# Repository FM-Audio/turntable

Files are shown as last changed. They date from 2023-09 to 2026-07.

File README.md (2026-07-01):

# FM-Audio ARTA Turntable

Automatischer, netzwerkfähiger Drehteller für Lautsprecher-Directivity- und Polar-Messungen mit ARTA.

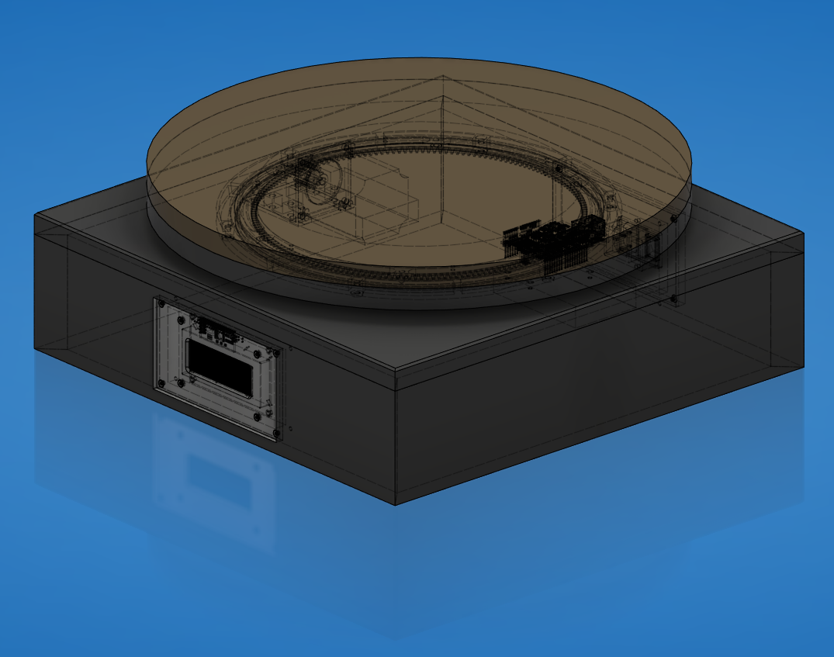
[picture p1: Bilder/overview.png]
FM-Audio Drehteller Projektübersicht


## Kurzbeschreibung

Bei der Entwicklung von Lautsprechern müssen Messungen häufig unter mehreren Winkeln durchgeführt werden, z. B. 0°, 15°, 30°, 45° oder 90°. Manuell ist das langsam, fehleranfällig und schlecht reproduzierbar.

Dieses Projekt automatisiert diesen Ablauf: ARTA steuert über ein externes Turntable-Programm einen Arduino-Drehteller an. Der Arduino fährt den Lautsprecher per Schrittmotor auf den gewünschten Winkel und zeigt IP-Adresse, Referenzfahrt und Position auf einem LCD an.

## Wofür ist das Projekt gedacht?

- Lautsprecherentwicklung
- Polar- und Directivity-Messungen
- ARTA-Gruppenmessungen
- reproduzierbare Winkelmessungen
- Messräume, bei denen Bedienplatz und Drehteller räumlich getrennt sind

## Funktionsprinzip

1. Der Arduino erhält per DHCP eine IP-Adresse.
2. Die IP-Adresse wird auf dem Display angezeigt.
3. Beim Start führt der Drehteller eine Referenzfahrt aus.
4. ARTA ruft das externe Turntable-Programm `turntable.exe` auf.
5. Das Programm sendet den Zielwinkel per UDP an den Arduino.
6. Der Arduino berechnet daraus die benötigten Motorschritte.
7. Der Schrittmotor fährt die gewünschte Position an.
8. Der Arduino sendet eine Rückmeldung zurück.

```text
ARTA -> turntable.exe -> Netzwerk/UDP -> Arduino -> TB6600 -> NEMA23 -> Drehteller
```

## Projektinhalt

| Pfad | Inhalt |
|---|---|
| [`Arduino/`](Arduino/) | Arduino-Sketch für Ethernet, UDP, Display, Referenzfahrt und Motorsteuerung |
| [`ARTA Turntable File/`](ARTA%20Turntable%20File/) | Windows-Datei `turntable.exe` für die ARTA-Anbindung inkl. benötigter DLLs |
| [`Bilder/`](Bilder/) | Anschlussplan, Screenshots und Fotos |
| [`DXF/`](DXF/) | CAD-/Fräs-/Laser-Dateien |
| [`STL/`](STL/) | 3D-Druck-Dateien für Halter und Abstandshalter |
| [`Bestellliste.xlsx`](Bestellliste.xlsx) | Stückliste / Einkaufsliste |
| [`Drehteller Dokument.docx`](Drehteller%20Dokument.docx) | ursprüngliche Projektdokumentation |
| [`ARTA Manual/`](ARTA%20Manual/) | ARTA-Dokumentation zur Turntable-/Polar-Messung |
| [`Drehteller.zip`](Drehteller.zip) | STEP/CAD-Datei |
| [`docs/downloads.md`](docs/downloads.md) | Download-Hinweise für Windows, Linux, ARTA, CAD/DXF/STL |

## Downloads

| Ziel | Download / Datei |
|---|---|
| Komplettes Projekt | GitHub `Code` → `Download ZIP` |
| REW-GUI für Windows | GitHub `Releases` → `FM-Audio-REW-Turntable-Windows.zip` |
| REW-GUI für Linux/CachyOS inkl. Desktop-Icon | GitHub `Releases` → `FM-Audio-REW-Turntable-Linux.zip` |
| ARTA-Treiber | [`ARTA Turntable File/turntable.exe`](ARTA%20Turntable%20File/turntable.exe) |
| STEP/CAD | [`Drehteller.zip`](Drehteller.zip) |
| DXF | [`DXF/`](DXF/) |
| STL | [`STL/`](STL/) |

Linux-Desktop-Starter: Im Linux-ZIP liegt `install_desktop_launcher_linux.sh`. Nach dem Ausführen erscheint der Starter als **FM-Audio REW Turntable** im Anwendungsmenü. Details: [`docs/downloads.md`](docs/downloads.md).

## Hardwareüberblick

| Komponente | Beispiel / Hinweis |
|---|---|
| Mikrocontroller | Arduino Ethernet oder Arduino Uno R3 + Ethernet Shield |
| Motor | NEMA23-Schrittmotor, ca. 2 Nm, 8-mm-Welle |
| Motortreiber | TB6600 CNC Stepper Driver |
| Netzteil Motor | Mean Well LRS-100-24, 24 V |
| Netzteil Logik | Mean Well 5 V, z. B. RS-15-5 oder vergleichbar |
| Display | I2C LCD 20x4, Adresse im Code aktuell `0x27` |
| Referenzsensor | Näherungssensor / Endlagensensor |
| Mechanik | Drehkranz, Zahnrad/Ritzel, MDF-/Alu-Platten, 3D-Druckhalter |

Die detaillierte Einkaufsliste liegt in [`Bestellliste.xlsx`](Bestellliste.xlsx).

## Pinbelegung Arduino

| Funktion | Arduino-Pin | Hinweis |
|---|---:|---|
| STEP / PULSE | D2 | zum TB6600 `PUL` / `STEP` |
| Referenzsensor | D3 | `INPUT_PULLUP`, erwartet HIGH/LOW-Wechsel |
| DIRECTION | D5 | zum TB6600 `DIR` |
| ENABLE | D8 | im Sketch definiert |
| LCD | I2C SDA/SCL | I2C-Display 20x4 |
| Netzwerk | Ethernet Shield / Arduino Ethernet | UDP-Port `10049` |

Mehr Details: [`docs/wiring.md`](docs/wiring.md)

## Wichtige Arduino-Werte

Im Sketch [`Arduino/Arta_TurntablemitStepperundDisplay20230803.ino`](Arduino/Arta_TurntablemitStepperundDisplay20230803.ino):

```cpp
unsigned int localPort = 10049;
float Stepsprograd = 65.75;
```

`Stepsprograd` ist der wichtigste Kalibrierwert. Er beschreibt, wie viele Motorschritte für 1° Drehtellerbewegung nötig sind.

Der Wert hängt ab von:

- Motorschritten pro Umdrehung
- Microstepping am TB6600
- Zahnrad/Ritzel
- Drehkranz-Übersetzung

Kalibrierung: [`docs/calibration.md`](docs/calibration.md)

## Arduino flashen

1. Arduino IDE installieren: <https://www.arduino.cc/en/software>
2. Benötigte Libraries installieren:
   - `Ethernet`
   - `EthernetUdp`
   - `LiquidCrystal_I2C`
   - `AccelStepper`
3. Datei öffnen:
   - [`Arduino/Arta_TurntablemitStepperundDisplay20230803.ino`](Arduino/Arta_TurntablemitStepperundDisplay20230803.ino)
4. Board und Port auswählen.
5. Sketch hochladen.
6. Arduino neu starten.
7. Auf dem Display prüfen:
   - DHCP erfolgreich?
   - IP-Adresse sichtbar?
   - Referenzfahrt abgeschlossen?

## ARTA einrichten

1. ARTA starten.
2. Menü öffnen:
   - `Setup` → `Rotating turntable`
3. `External` auswählen.
4. Als Turntable-Programm eintragen:
   - `ARTA Turntable File/turntable.exe`
5. Falls ARTA die Datei nicht direkt auswählbar macht, den Pfad manuell eintragen.

Mehr Details: [`docs/arta-setup.md`](docs/arta-setup.md)

## Messung durchführen

1. ARTA öffnen.
2. `Record` → `Spatial impulse response group record`
3. Turntable Driver auswählen.
4. Messordner erstellen und auswählen.
5. Winkelauflösung wählen, z. B. `15°`.
6. Endwinkel wählen, z. B. `45°`, `90°` oder `180°`.
7. Pause setzen, z. B. `3 s`.
8. Dateinamen prüfen.
9. Messung starten.

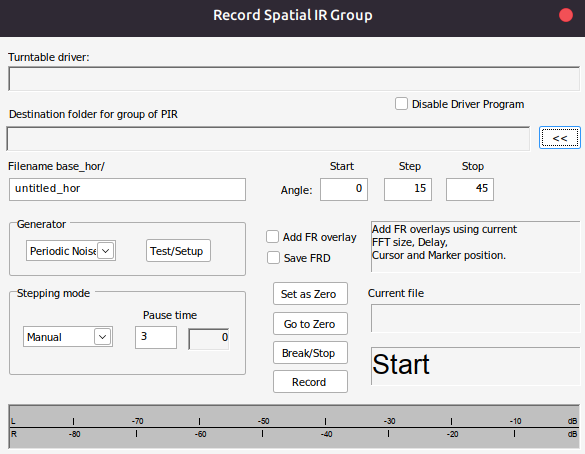
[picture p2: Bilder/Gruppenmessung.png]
ARTA Gruppenmessung


## REW-Integration

REW 5.40+ besitzt eine HTTP-API. Dadurch kann der vorhandene Arduino-Drehteller auch mit Room EQ Wizard genutzt werden.

Das Python-Script liegt hier:

```text
software/rew_turntable/rew_turntable_runner.py
```

Dokumentation: [`docs/rew-integration.md`](docs/rew-integration.md)

Kurzbeispiel für den aktuell geprüften Turntable:

```bash
python software/rew_turntable/rew_turntable_runner.py \
  --turntable-ip 192.168.178.191 \
  --mode manual \
  --angles 0:180:15
```

Für die Werkstattbedienung mit frei einstellbarem Start-/Endwinkel, Schrittweite und REW-Frequenzbereich gibt es zusätzlich:

```bash
python software/rew_turntable/rew_turntable_gui.py
```

Unter Windows und Linux gibt es vorbereitete Download-Pakete:

| Variante | Download/Start |
|---|---|
| Fertige Windows-EXE | GitHub Release `FM-Audio-REW-Turntable-Windows.zip` herunterladen und `FM-Audio-REW-Turntable.exe` starten |
| Linux/CachyOS-Paket | GitHub Release `FM-Audio-REW-Turntable-Linux.zip` herunterladen, `run_gui_linux.sh` starten oder `install_desktop_launcher_linux.sh` für den Desktop-Starter ausführen |
| Python-Version | `software\rew_turntable\run_gui_windows.bat` doppelklicken oder unter Linux `software/rew_turntable/run_gui_linux.sh` starten |

Die Windows-EXE und das Linux-Paket werden automatisch über `.github/workflows/build-windows.yml` gebaut.

## Dokumentation

| Dokument | Zweck |
|---|---|
| [`docs/downloads.md`](docs/downloads.md) | Download-Pakete und Startdateien für Windows/Linux |
| [`docs/build-guide.md`](docs/build-guide.md) | Aufbau und Projektüberblick |
| [`docs/wiring.md`](docs/wiring.md) | Anschluss, Pins und Verdrahtung |
| [`docs/arta-setup.md`](docs/arta-setup.md) | Einrichtung in ARTA |
| [`docs/rew-integration.md`](docs/rew-integration.md) | REW-API-Anbindung und Python-Script |
| [`docs/calibration.md`](docs/calibration.md) | Kalibrierung von `Stepsprograd` |
| [`docs/troubleshooting.md`](docs/troubleshooting.md) | Fehlersuche |

## Sicherheitshinweis

In diesem Projekt werden Netzteile verwendet, die mit Netzspannung betrieben werden können.

**230-V-Arbeiten dürfen nur von fachkundigen Personen durchgeführt werden.**

Vor dem Einschalten prüfen:

- Netzteile korrekt angeschlossen?
- 24-V- und 5-V-Seite getrennt und sauber verdrahtet?
- gemeinsame Masse nur dort verbunden, wo sinnvoll?
- Motortreiber korrekt eingestellt?
- Not-Aus / Abschaltmöglichkeit vorhanden?

## Bekannte Verbesserungsmöglichkeiten

- Python-Quellcode zu `turntable.exe` ergänzen.
- README-Bilder weiter optimieren und verkleinern.
- GitHub Release mit versionierten ZIP-Dateien ergänzen, damit Nutzer nicht auf zeitlich begrenzte Actions-Artefakte angewiesen sind.
- Arduino-Code stärker kommentieren und Konstanten in einen Konfigurationsblock verschieben.
- Mechanik-Maße und Montage-Reihenfolge noch ausführlicher dokumentieren.

## Lizenz

Dieses Projekt steht unter der [`FM-Audio Non-Commercial Source License 1.0`](LICENSE).

Kurzfassung:

| Erlaubt | Nicht erlaubt |
|---|---|
| private Nutzung | kommerzielle Nutzung |
| Lernen / Evaluieren / Hobby | Verkauf von Produkten, Kits, CAD-Dateien oder Software |
| nicht-kommerzielle Änderungen | bezahlte Fertigung, Messung, Kalibrierung, Support oder Beratung |
| nicht-kommerzielle Weitergabe unter gleicher Lizenz | Nutzung in kommerziellen Kunden-/Firmenprojekten |

Es wird **keine Patentlizenz** gewährt. Für kommerzielle Nutzung, Patentrechte oder Sonderfreigaben bitte schriftlich anfragen: `turntable@fm-audio.eu`.

## Credits

FM-Audio — Stefan Weltermann, Nils Hitschke

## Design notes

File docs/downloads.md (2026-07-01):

# Downloads

Dieses Repository enthält Hardware-Dateien, Firmware und Software-Starter für den FM-Audio Drehteller.

## Schnellübersicht

| Paket / Datei | Zweck | Wo herunterladen? |
|---|---|---|
| Komplettes Projekt | Firmware, CAD, Bilder, Doku, Software | GitHub: `Code -> Download ZIP` |
| Windows GUI | Fertige `FM-Audio-REW-Turntable.exe` für REW | GitHub `Releases` -> `FM-Audio-REW-Turntable-Windows.zip` |
| Linux GUI + Desktop-Icon | Python/Tkinter-GUI, Shell-Starter, `.desktop`-Launcher | GitHub `Releases` -> `FM-Audio-REW-Turntable-Linux.zip` |
| ARTA-Treiber | Klassische ARTA-Datei `turntable.exe` | Im Repo: `ARTA Turntable File/turntable.exe` |
| STEP/CAD | STEP-Datei für den Drehteller | Im Repo: `Drehteller.zip` |
| DXF-Dateien | Fräs-/Laser-Dateien | Im Repo: `DXF/` |
| STL-Dateien | 3D-Druckteile | Im Repo: `STL/` |

## Windows

1. Auf GitHub den Bereich `Releases` öffnen:

```text
https://github.com/FM-Audio/turntable/releases
```

2. Das Windows-Paket herunterladen:

```text
FM-Audio-REW-Turntable-Windows.zip
```

3. ZIP entpacken und starten:

```text
FM-Audio-REW-Turntable.exe
```

## Linux / CachyOS / Arch

1. Auf GitHub den Bereich `Releases` öffnen:

```text
https://github.com/FM-Audio/turntable/releases
```

2. Das Linux-Paket herunterladen:

```text
FM-Audio-REW-Turntable-Linux.zip
```

3. ZIP entpacken.
4. Voraussetzungen installieren, z. B. auf CachyOS/Arch:

```bash
sudo pacman -S python tk
```

5. Direkt starten:

```bash
chmod +x run_gui_linux.sh
./run_gui_linux.sh
```

6. Optional Desktop-Icon installieren:

```bash
chmod +x install_desktop_launcher_linux.sh
./install_desktop_launcher_linux.sh
```

Danach gibt es einen Anwendungsstarter:

```text
FM-Audio REW Turntable
```

## Actions-Artefakte

Zusätzlich erzeugt der Workflow `Build GUI Downloads` weiterhin GitHub-Actions-Artefakte. Für normale Nutzer sind aber die Dateien im Bereich `Releases` der empfohlene Download-Weg.

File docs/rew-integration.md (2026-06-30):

# REW-Integration für den FM-Audio Turntable

Der bestehende Drehteller wurde ursprünglich für ARTA gebaut. REW 5.40+ besitzt inzwischen eine HTTP-API, dadurch kann der Drehteller auch mit REW automatisiert werden.

## Kurzfazit

Ja, die Anbindung ist möglich.

Für den vollautomatischen Betrieb muss in REW eine **Pro-Upgrade-Lizenz** hinterlegt sein. Das ist wichtig für Benutzer des GitHub-Repos:

- automatische Sweeps per API: `POST /measure/command {"command": "SPL"}`
- Sweep-Frequenzbereich per API setzen: `PUT /measure/sweep/configuration`

Ohne Pro bleibt der manuelle Modus nutzbar: Das Programm dreht den Teller und wartet, bis der Benutzer in REW eine Messung gestartet/gespeichert hat.

Es gibt drei Betriebsarten:

| Modus | Voraussetzung | Ablauf |
|---|---|---|
| `auto` | REW 5.40+ API + REW Pro Upgrade | Programm dreht den Teller, startet den REW-Sweep per API, wartet bis die Messung fertig in REW erscheint, dreht weiter |
| `manual` | REW 5.40+ API, keine Pro-Lizenz nötig | Programm dreht den Teller, Bediener startet Messung in REW, Programm erkennt neue Messung |
| `turntable-only` | nur Netzwerk zum Arduino | Programm dreht nur den Teller |

Wichtig: Laut REW-Dokumentation sind GET-Zugriffe frei nutzbar. Schreibende API-Aktionen wie Sweep-Konfiguration und automatisierte Sweep-Messungen benötigen das REW-Pro-Upgrade.

## Architektur

```text
REW 5.40+ API  <---- HTTP localhost:4735 ---->  rew_turntable_runner.py
                                                        |
                                                        | UDP Port 10049
                                                        v
Arduino Turntable  <---- TB6600 ---->  NEMA23 / Drehteller
```

Der Arduino-Code muss dafür zunächst nicht geändert werden. Er versteht bereits UDP-Kommandos mit Winkelwerten.

## Vorhandenes Arduino-Protokoll

Im Arduino-Sketch:

```cpp
unsigned int localPort = 10049;
float Stepsprograd = 65.75;
```

Der Arduino erwartet per UDP einen Winkel als ASCII-Text, z. B.:

```text
0
15
30
-15
```

Danach fährt er auf diese Position und sendet eine kurze Textantwort zurück.

## REW API starten

### Windows

```powershell
"C:\Program Files\REW\roomeqwizard.exe" -api
```

Oder in den REW-Einstellungen:

```text
Preferences -> API -> Start API server
```

Standardadresse:

```text
http://127.0.0.1:4735
```

Die Swagger-/API-Doku ist dann im Browser erreichbar:

```text
http://localhost:4735
```

### Prüfen

Auf dem REW-PC:

```powershell
curl http://127.0.0.1:4735/application/commands
```

Wenn JSON zurückkommt, läuft die API.

## REW wie ARTA nutzen

ARTA hat eine eingebaute Gruppenmessung:

```text
Record -> Spatial impulse response group record
```

Dort stellt man z. B. `0°` bis `90°` in `15°`-Schritten ein. ARTA ruft dann für jeden Winkel `turntable.exe` auf.

REW hat aktuell keine identische eingebaute Turntable-Dialogbox. Die entsprechende Lösung ist daher ein **kleiner externer Ablaufstarter**:

```text
rew_turntable_runner.py
```

Der Ablaufstarter übernimmt das, was bei ARTA die Gruppenmessung macht:

1. Winkelreihe erzeugen, z. B. `0, 15, 30, 45, 60, 75, 90`.
2. Drehteller per UDP auf den Zielwinkel fahren.
3. Einschwingzeit abwarten.
4. REW-Messung starten oder auf manuell gestartete REW-Messung warten.
5. Messung mit Winkelname/Notiz versehen.
6. Zum nächsten Winkel gehen.

Damit sieht der REW-Ablauf praktisch so aus:

```bash
python software/rew_turntable/rew_turntable_runner.py \
  --turntable-ip 192.168.178.191 \
  --mode manual \
  --angles 0:90:15 \
  --settle-s 3 \
  --name-template "Angle {angle} deg"
```

Für den Standardfall liegt zusätzlich ein Starter-Script im gleichen Ordner:

```bash
software/rew_turntable/run_0_90_15_manual.sh
```

Für den normalen Werkstattbetrieb gibt es außerdem ein kleines Desktop-Fenster:

```bash
python software/rew_turntable/rew_turntable_gui.py
```

Dort können Startwinkel, Endwinkel, Schrittweite und der REW-Frequenzbereich frei eingegeben werden, z. B.:

```text
Start: 0°
Ende:  135°
Schritt: 10°
Startfrequenz: 2000 Hz
Endfrequenz: 20000 Hz
```

Der Frequenzbereich wird über die REW-API gesetzt:

```http
PUT /measure/sweep/configuration
{"startFrequency": 2000, "endFrequency": 20000, "length": "512k"}
```

Das ist z. B. für Hochtöner sinnvoll, damit kein unnötiger Tieftonanteil im Sweep liegt.

Das erzeugt die Reihe:

```text
0°, 10°, 20°, 30°, 40°, 50°, 60°, 70°, 80°, 90°, 100°, 110°, 120°, 130°, 135°
```

Wenn der Endwinkel nicht genau auf dem Raster liegt, wird er als letzter Winkel zusätzlich angefahren. So funktioniert `0°` bis `135°` mit `10°` Schritten wie erwartet.

Für den Bediener ist das die REW-Entsprechung zu ARTA `Start` in der Gruppenmessung.

## Script verwenden

Das Script liegt hier:
```text
software/rew_turntable/rew_turntable_runner.py
```

### Nur Drehteller testen

```bash
python software/rew_turntable/rew_turntable_runner.py \
  --turntable-ip 192.168.178.191 \
  --mode turntable-only \
  --angles 0
```

### Manuell mit REW messen

Dieser Modus braucht keine REW-Pro-Lizenz für automatische Sweeps.

```bash
python software/rew_turntable/rew_turntable_runner.py \
  --turntable-ip 192.168.178.191 \
  --mode manual \
  --angles 0:180:15 \
  --settle-s 3
```

Ablauf:

1. Script fährt Winkel 0° an.
2. Script wartet 3 Sekunden.
3. Bediener startet in REW die Messung.
4. Script erkennt, dass eine neue Messung in REW entstanden ist.
5. Script fährt zum nächsten Winkel.
6. Wiederholen bis Endwinkel erreicht ist.

### Vollautomatisch mit REW Pro

```bash
python software/rew_turntable/rew_turntable_runner.py \
  --turntable-ip 192.168.178.191 \
  --mode auto \
  --angles 0:180:15 \
  --settle-s 3 \
  --start-frequency 2000 \
  --end-frequency 20000 \
  --sweep-length 512k
```

Dieser Modus läuft so ab:

1. REW-Sweepbereich konfigurieren, z. B. 2000–20000 Hz.
2. Drehteller auf den Zielwinkel fahren.
3. Einschwingzeit abwarten.
4. REW-API-Befehl senden:

```http
POST /measure/command
{"command": "SPL"}
```

5. Warten, bis in REW eine neue Messung unter `/measurements` erscheint.
6. Erst dann zum nächsten Winkel fahren.

Wenn REW meldet, dass die Lizenz nicht ausreicht, `--mode manual` verwenden oder REW Pro aktivieren.

## Wenn REW auf einem anderen Rechner läuft

Die REW-API ist standardmäßig nur lokal erreichbar. Am einfachsten ist daher:

- Python-Script direkt auf dem REW-PC ausführen.
- Der REW-PC muss den Arduino per Netzwerk erreichen können.

Alternativ kann REW mit Host-Bindung gestartet werden:

```powershell
"C:\Program Files\REW\roomeqwizard.exe" -api -host "0.0.0.0"
```

Dann Firewall und Netzwerkfreigabe beachten.

## Aktuell geprüfter Turntable

Im lokalen Netzwerk wurde der Arduino anhand der im Sketch definierten MAC-Adresse gefunden:

```text
MAC: b8:96:74:01:02:03
IP:  192.168.178.191
Port: 10049/UDP
```

Ein sicherer Test mit Winkel `0` lieferte eine UDP-Antwort vom Arduino.

## Nächste technische Verbesserungen

- Arduino-Antwort verlängern: Der aktuelle Antwortpuffer ist sehr kurz und schneidet den Text ab.
- Optional Statuskommando ergänzen, z. B. `status`, ohne Bewegung.
- Optional `home`/`reference`-Kommando ergänzen.
- Optional Zielwinkel erst bestätigen, wenn die Position wirklich erreicht wurde.
- Python-Script später als Windows-EXE paketieren.

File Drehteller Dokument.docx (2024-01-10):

ARTA Drehteller

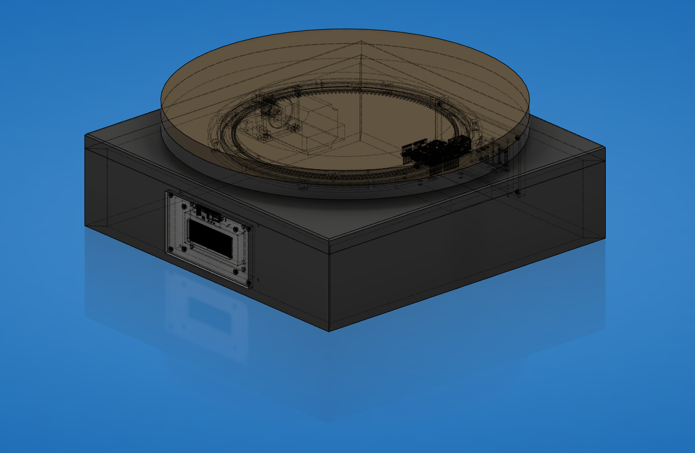
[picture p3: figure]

Problemstellung:

Beim Entwickeln von Lautsprechern und zum Beurteilen des Abstrahlverhaltens ist es notwendig verschiedene Winkel eines Lautsprechers zu messen und zu untersuchen.

Dies stellt man typischerweise mit manuellen Drehtellern an.

Im professionellen Bereich arbeitet man mit automatisierten Drehtellern, zum Teil sogar mit mehreren, um Ballonmessungen anfertigen zu können.

Bei der manuellen Variante, muss die Messung in der Regel auch manuell gestartet, ein Filename benannt und der Lautsprecher weitergedreht werden. Entwicklungen sind häufig ein iterativer Prozess und müssen dann mehrfach wiederholt werden.

Um sich Zeit zu sparen, haben wir uns einen automatisierten Drehteller entwickelt, welcher an den ARTA Drehteller aus dem ARTA Annex angelehnt ist.

Folgende Punkte haben uns aber gestört, bzw. wollten wir anders machen:

1. Standard Hardware

Das Ziel war es mit typischer und gut erhältlicher und günstiger Hardware zu arbeiten.

Daher haben wir uns für den Arduino R3 mit Ethernet Shield bzw. für ein Arduino Ethernet mit USB2Serial Board entschieden. Die Bespielung des ATMega 328 funktioniert dabei über die erhältliche Arduino IDE Software. Als Schrittmotor kam ein günstiger Nema23 mit 2Nm Drehmoment in Frage mit einem 21 Zahn Stirnrad.

2. Netzwerkgebunde Software

Bei semi -und professionellen Messungen ist oft der Messraum vom Bedienraum getrennt.

Die klassischen Lösung sieht eine USB Schnittstelle vor, die nicht ewig verlängert werden kann. Meist ist nach 5Metern Schluss. Daher bezieht unsere Lösung eine IP Adresse über einen DHCP Server. Es muss nur ein Netzwerkkabel angeschlossen werden und die IP Adresse wird dann über das eingebaut Display angezeigt. So ist es möglich entfernte Strecken zu überwinden.

3. Optische Anzeige

Ein Display ist zwar nicht zwangsläufig notwendig, allerdings ist es schön ein Feedback vom Drehteller zu bekommen. Angezeigt werden: Die aktuelle IP Adresse, Referenzfahrt, Referenzfahrt durchgeführt und die aktuelle Position bzw. deren Gradzahl.

Im Anhang findet ihr folgende Dinge:

DXF Zeichnungen von Displayplatte, Halteplatte Schrittmotor, Rückplatte

STL Files für Abstandshalter und Rückplatte

Stückliste und Bezugsmöglichkeiten

Programmcode Arduino

Programmcode Python Anbindung ARTA

Das Projekt wird als OpenSource veröffentlicht und es ist jedem frei die Software nach seinen Belieben zu ändern und anders zu gestalten.

Installation des Programms auf dem Arduino

1. Runterladen der Arduino IDE Software

https://www.arduino.cc/en/software

2. Öffnen der Arta_Turntable_xx.ino

3. Board auswählen

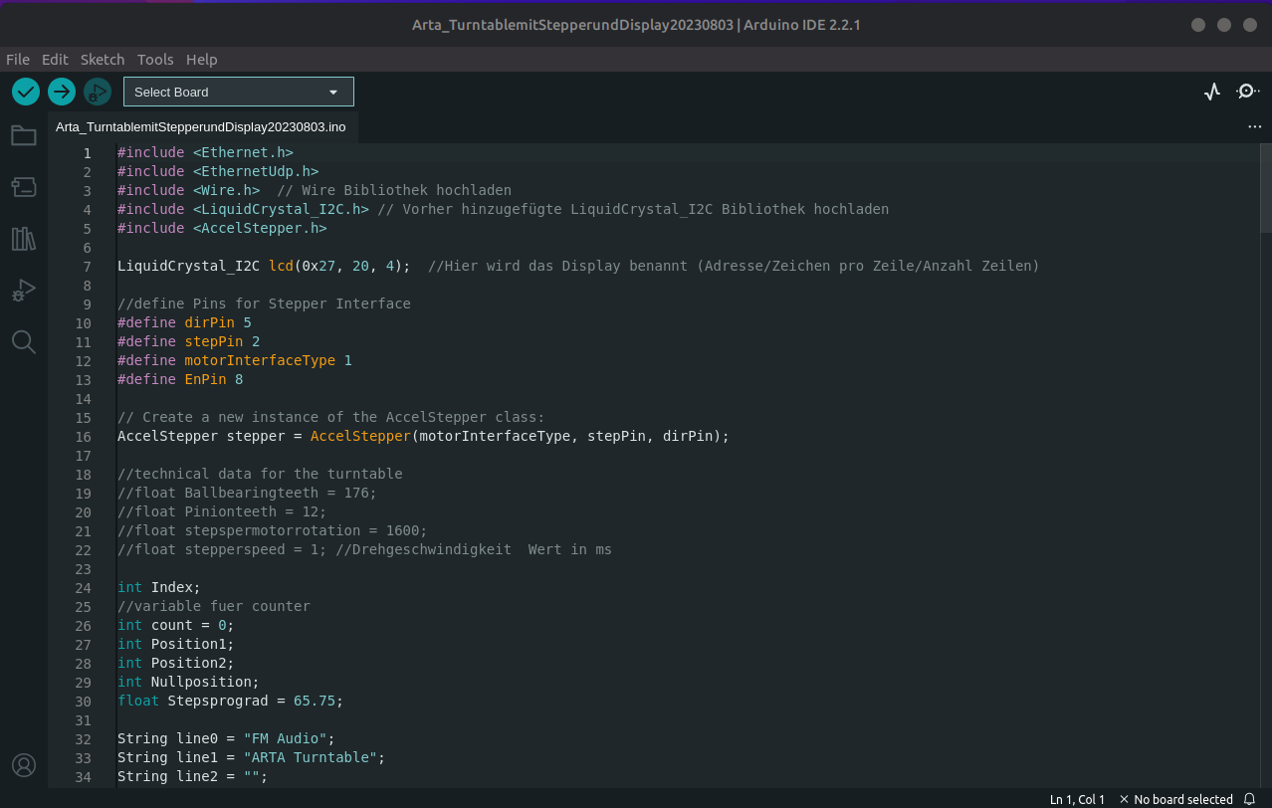
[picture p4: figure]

4. Upload des Codes auf den Arduino

ARTA Turntable Programm integrieren

1. Starte die ARTA Messsoftware

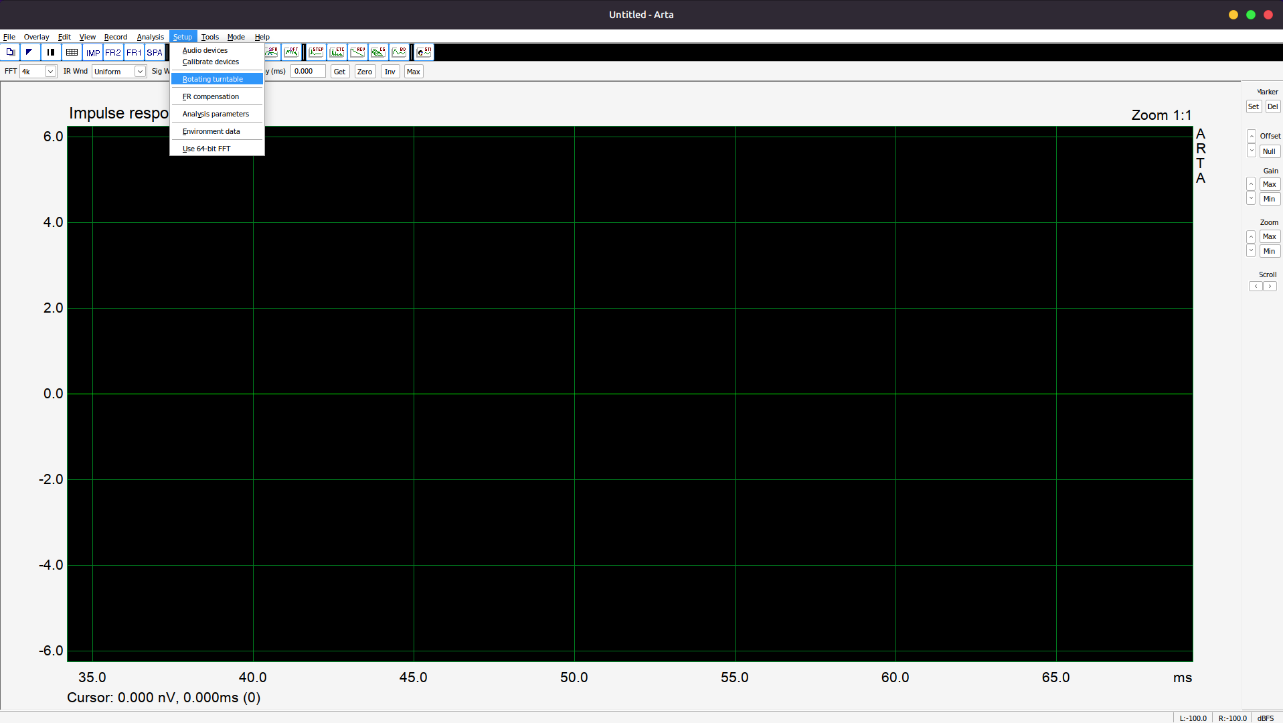
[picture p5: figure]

2. Setup > Rotating turntable

3. Auswahl External > Browse File > turntable.exe aus Ordner wählen.

Die .exe Datei kann nicht angeklickt werden sondern muss manuell eintragen werden.

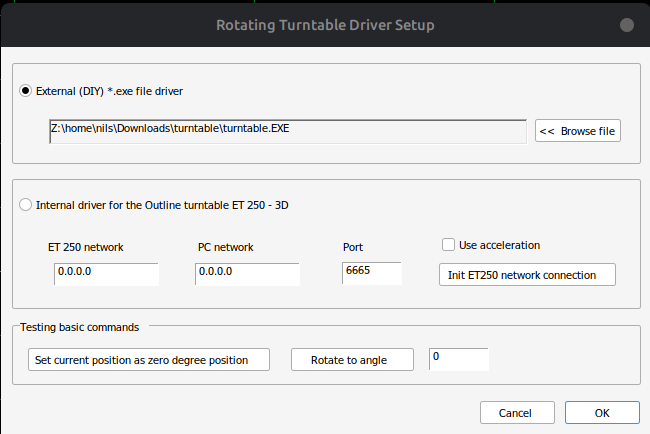
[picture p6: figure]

Messung durchführen


1. Record > Spatial impulse response group record

2. Turntable driver auswählen

3. Ordner für die PIR Messung erstellen und auswählen

4. Winkelauflösung einstellen (Standard 15Grad)

5. Endwinkel angeben (Standard 45Grad)

6. Pause von 3 Sekunden eintragen

7. Gegenbefalls Filename abändern

8. Start

Anschließen und Verbinden des Schrittmotors und der Kabel

Schrittmotor auf Arduino

stepPin = 2

dirPin = 5

EnPin = 8

Spannungsteiler = 3

Widerstände =

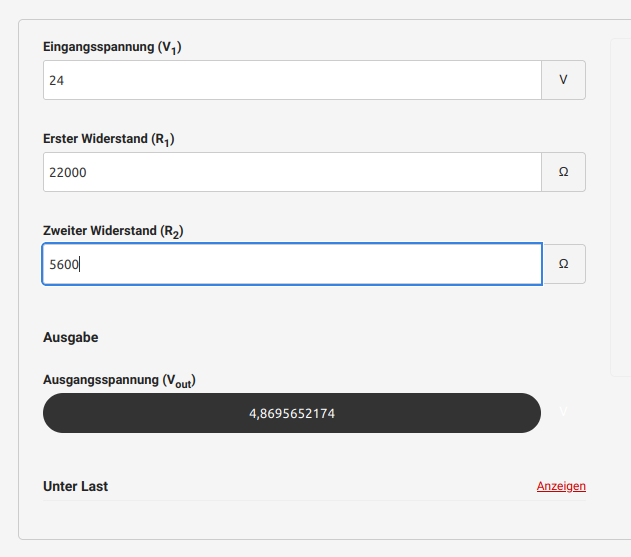
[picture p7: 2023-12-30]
Bilder/Spannungsteiler.png

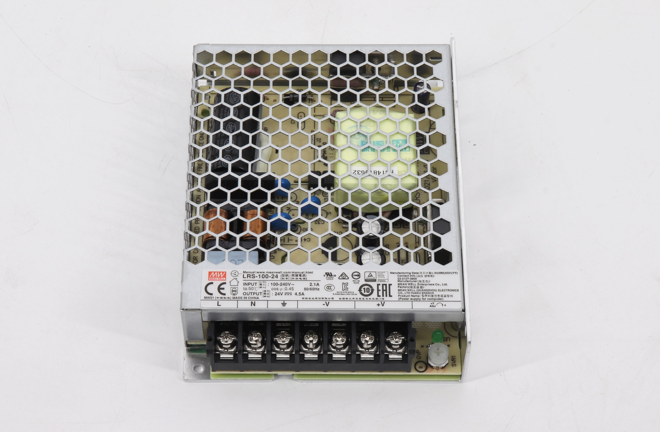
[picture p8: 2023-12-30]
Bilder/LRS24V.jpg

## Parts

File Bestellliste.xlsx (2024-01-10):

Stückliste | Bauteil | Bezeichnung | Preis | Anbieter | Hersteller | Bemerkung
1 | Zahnkranz | https://www.drehteller.com/drehkraenze/alu-druckguss/61/drehkranz-alu-druckguss-330-mm-sandgestrahlt?c=15 | 36.95 € | Hefter Fertigungstechnik
2 | Mikrocontroller | https://store.arduino.cc/products/arduino-ethernet-shield-2 | 17.99 € | Amazon | Arduino
 | Mikrocontroller |  |  | Amazon | Arduino | Alternative zu 1
3 | Zahnrad | https://www.maedler.de/Article/21801100 | 15.15 € | Hefter Fertigungstechnik | Mädler | 1600-0300.01 | Außen 21mm, Bohrung 8mm, Werkstoff C45
4 | Aluwinkel | Baumarkt/ebay | 5.00 € | ebay |  | Muss angepasst werden
5 | Holz | MDF schwarz | 15.00 € | Baumarkt
6 | Schrauben | Holzschrauben 4x25mm | 5.00 € | Baumarkt
7 | Schrittmotor | 23HS8430D8P1-5 | 13.29 € | ACT Motor |  | 8mm Aufnahme nicht 6mm
8 | Netzteil 12V | Schaltnetzteil LRS-100-24 - 108W 24V | 22.00 € | Amazon | Meanwell
9 | Netzteil 5V | Schaltnetzteil RS-15-5 3A | 10.97 € | Pollin | Meanwell
10 | Kabel | Steckboard-Verbindungsleitungen | 2.96 € | Pollin
11 | Schrittmotortreiber | Schrittmotortreiber TB6600CNC | 11.55 € | ebay
12 | Widerstände | Widerstände für Spannungsteiler | 0.40 € | Pollin
13 | Abstandshalter | Abstandsbolzen Polyamid 5,6mm M3x0,5 8mm | 0.07 € | Pollin
14 | Stiftleiste | Stiftleiste 2x20Polig | 0.32 € | Pollin | zum anlöten der Kabel
15 | Steckbrücken | Steckbrücken Sortiment | 3.60 € | Pollin | Kabel

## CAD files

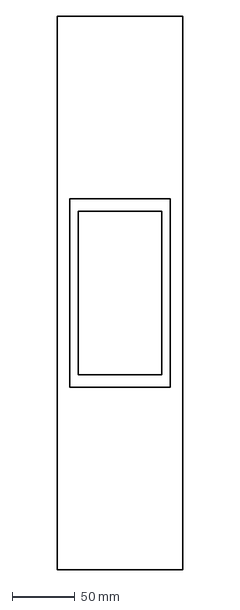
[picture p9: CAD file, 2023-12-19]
DXF/Kasten_Front_2004.dxf
100.0 x 440.0 mm

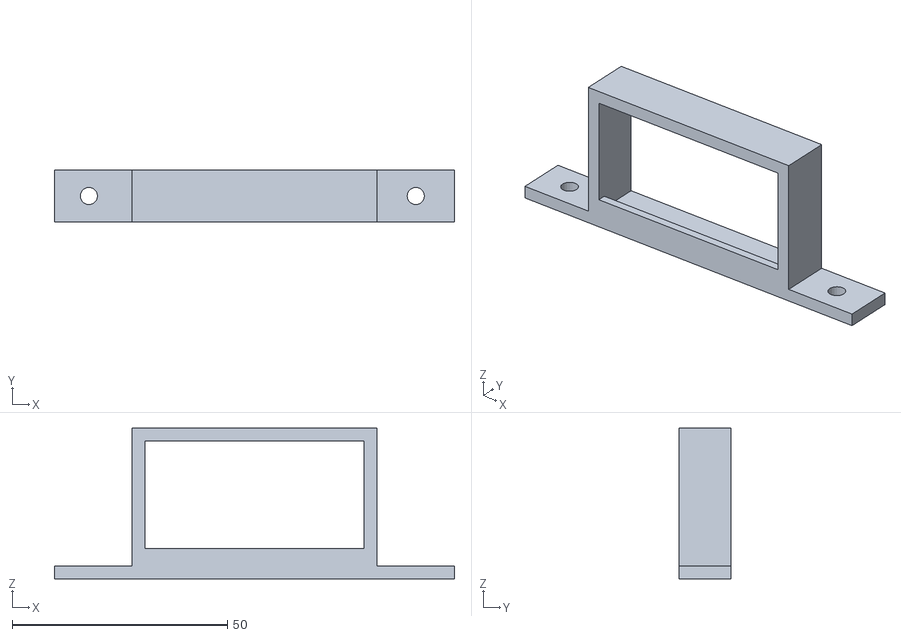
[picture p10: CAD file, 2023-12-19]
STL/Mean_Well_RS_Holder_Rear.stl
93.0 x 12.0 x 35.0

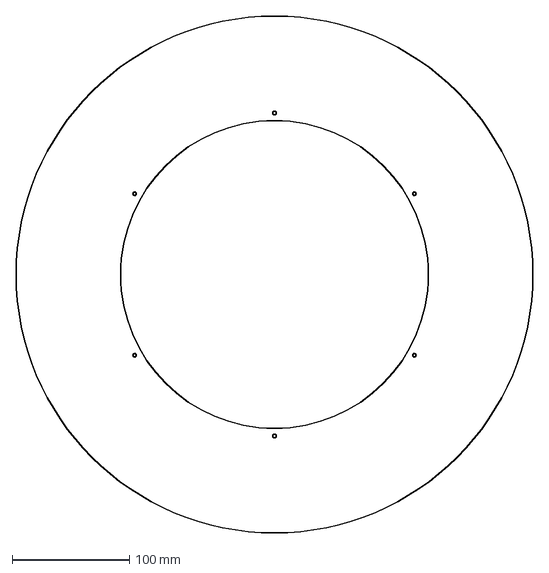
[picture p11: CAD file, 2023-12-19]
DXF/Zwischenring3_neu.dxf
440.0 x 440.0 mm

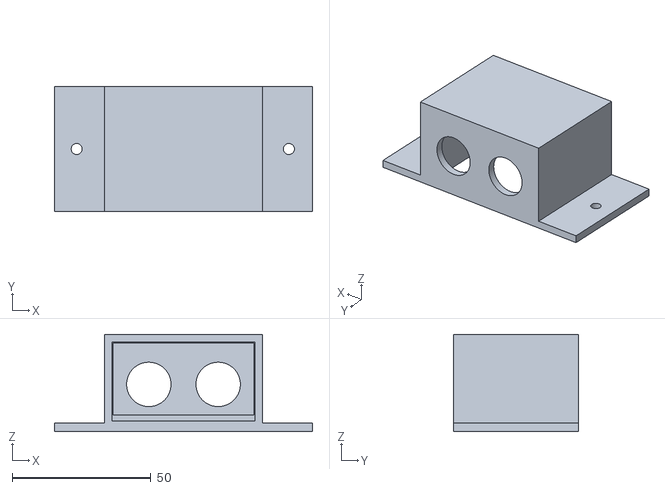
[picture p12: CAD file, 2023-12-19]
STL/Mean_Well_RS_Holder_Front.stl
93.0 x 45.0 x 35.0

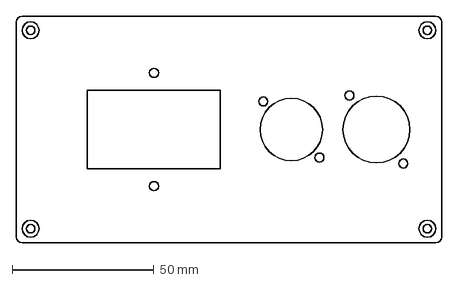
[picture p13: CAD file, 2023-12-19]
DXF/Displayplatte_Neutrik.dxf
150.0 x 80.0 mm

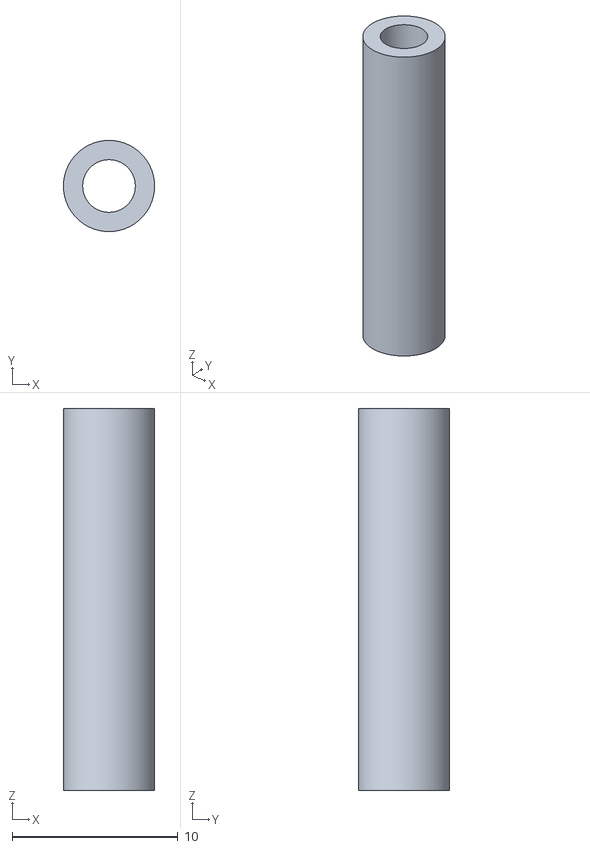
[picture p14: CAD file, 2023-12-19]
STL/Abstandshalter Arduino.stl
5.50 x 5.50 x 23.0

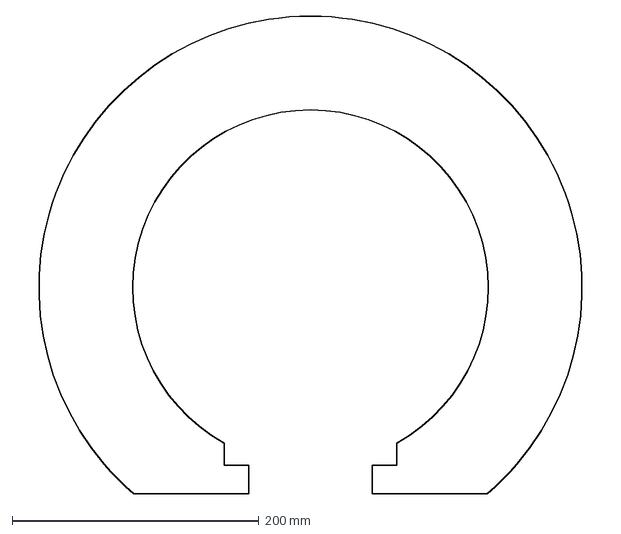
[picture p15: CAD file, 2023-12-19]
DXF/Zwischenring2.dxf
476.5 x 387.0 mm

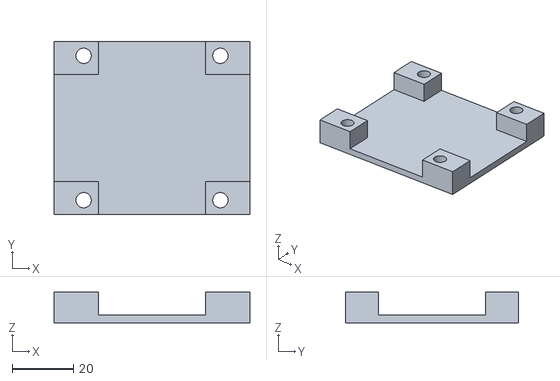
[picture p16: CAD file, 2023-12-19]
STL/Abstandshalter Schrittmotor.stl
64.0 x 56.4 x 10.0

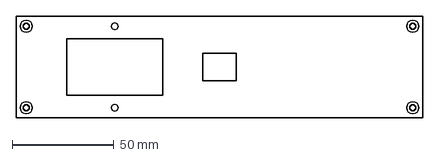
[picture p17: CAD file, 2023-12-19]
DXF/Displayplatte_Rück.dxf
200.0 x 50.0 mm

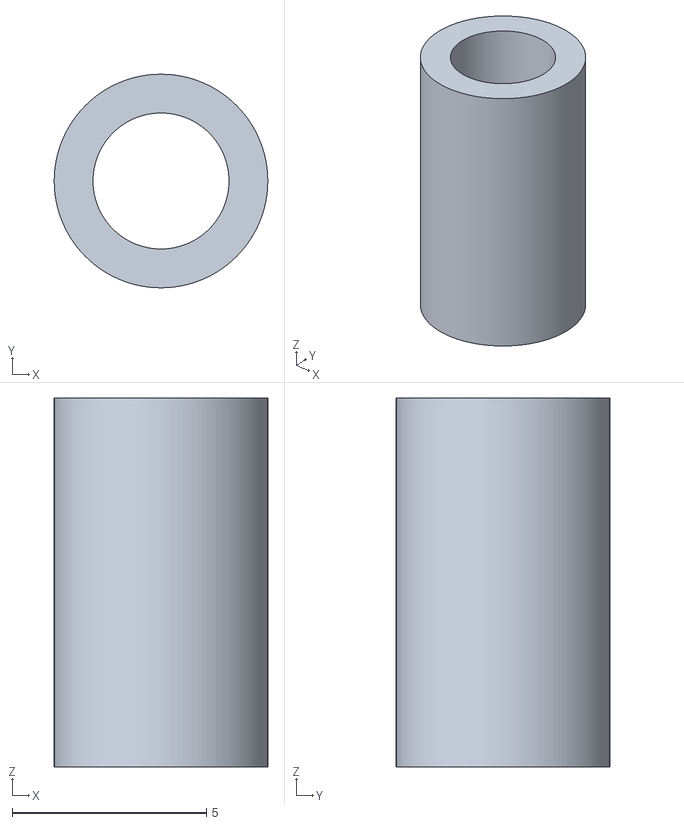
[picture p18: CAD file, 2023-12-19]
STL/Abstandshalter Display.stl
5.50 x 5.50 x 9.50

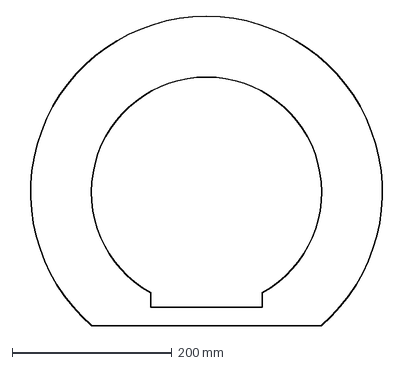
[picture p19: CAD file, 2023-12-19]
DXF/Zwischenring.dxf
476.5 x 387.0 mm

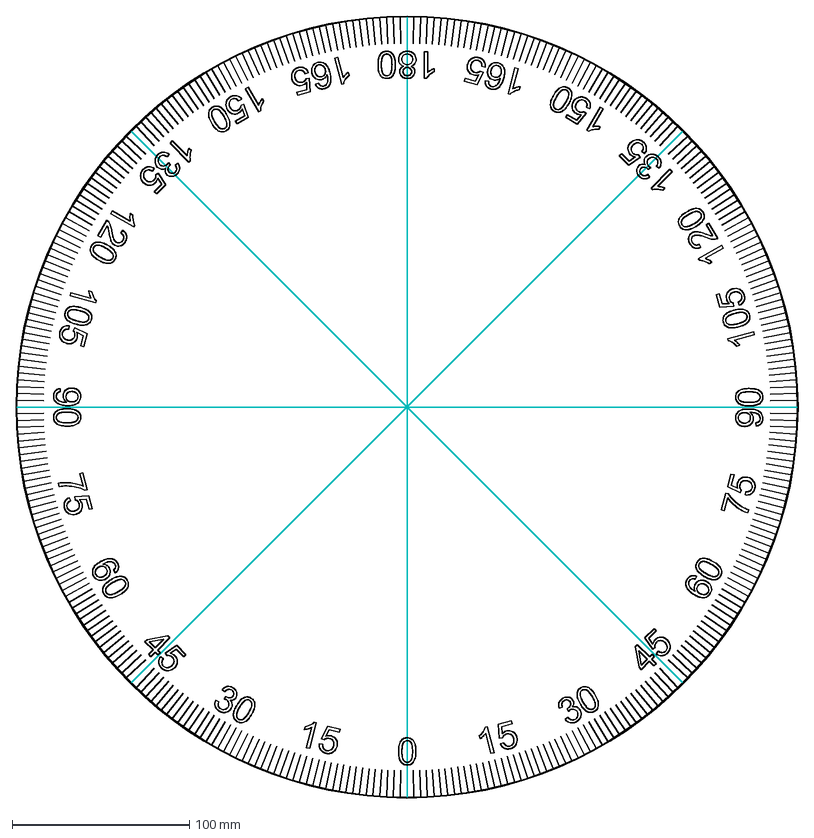
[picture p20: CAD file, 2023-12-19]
DXF/Deckplatte Skala.dxf
441.0 x 441.0 mm

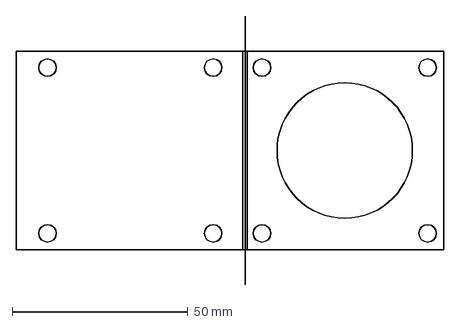
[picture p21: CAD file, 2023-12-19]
DXF/Winkel.dxf
121.7 x 76.4 mm

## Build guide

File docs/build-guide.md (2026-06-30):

# Aufbau und Projektüberblick

Dieser Drehteller wurde entwickelt, um Lautsprecher bei ARTA-Messungen automatisch auf definierte Winkel zu drehen.

## Problem

Für Directivity- und Polar-Messungen müssen Lautsprecher unter vielen Winkeln gemessen werden. Bei einer manuellen Lösung muss man nach jeder Messung:

1. Messung stoppen oder neu starten,
2. Dateinamen kontrollieren,
3. Lautsprecher manuell weiterdrehen,
4. nächsten Winkel messen.

Das ist langsam und bei wiederholten Entwicklungszyklen unpraktisch.

## Ziel der Lösung

Die Lösung soll:

- mit gut verfügbaren Standardteilen funktionieren,
- per Netzwerk steuerbar sein,
- unabhängig von langen USB-Kabeln arbeiten,
- den aktuellen Status sichtbar anzeigen,
- direkt mit ARTA nutzbar sein.

## Aufbau

Die Mechanik besteht aus einem Drehkranz, einem Schrittmotor mit Ritzel und einer Trägerplatte. Der Schrittmotor wird über einen TB6600-Treiber angesteuert.

Der Arduino übernimmt:

- Netzwerkverbindung über Ethernet,
- Empfang des Zielwinkels per UDP,
- Referenzfahrt über einen Sensor,
- Umrechnung von Winkel in Motorschritte,
- Ansteuerung des Schrittmotors,
- Anzeige von IP-Adresse und Position auf dem LCD.

## Dateiübersicht

| Bereich | Datei / Ordner |
|---|---|
| Firmware | `Arduino/Arta_TurntablemitStepperundDisplay20230803.ino` |
| ARTA-Treiber | `ARTA Turntable File/turntable.exe` |
| Anschlussplan | `Bilder/Anschlussplan.png` |
| Stückliste | `Bestellliste.xlsx` |
| CAD/DXF | `DXF/` |
| 3D-Druck | `STL/` |
| STEP/CAD | `Drehteller.zip` |

## Startablauf

1. Arduino startet.
2. Display wird initialisiert.
3. Arduino versucht per DHCP eine IP-Adresse zu erhalten.
4. IP-Adresse wird angezeigt.
5. UDP-Port `10049` wird geöffnet.
6. Referenzfahrt startet.
7. Drehteller ist bereit für ARTA.

## Hinweis zur Mechanik

Der Wert `Stepsprograd` im Arduino-Code muss zur realen Übersetzung passen. Wenn Zahnrad, Motor, Microstepping oder Drehkranz geändert werden, muss dieser Wert neu kalibriert werden.

Siehe: [`calibration.md`](calibration.md)

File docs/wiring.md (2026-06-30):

# Verdrahtung und Anschluss

Der Anschlussplan liegt hier:

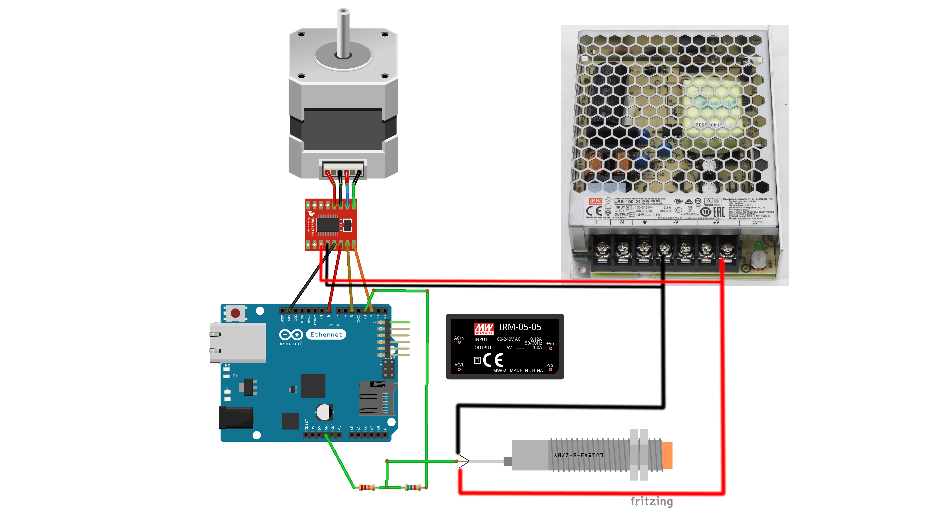
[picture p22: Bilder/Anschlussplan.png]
Anschlussplan


## Arduino-Pins

| Funktion | Arduino-Pin | Beschreibung |
|---|---:|---|
| STEP / PULSE | D2 | Schrittimpuls zum TB6600 |
| Referenzsensor | D3 | Eingang für Referenzpunkt, im Code `INPUT_PULLUP` |
| DIRECTION | D5 | Richtungssignal zum TB6600 |
| ENABLE | D8 | Enable-Pin, im Code definiert |
| LCD | I2C SDA/SCL | 20x4 I2C-Display |
| Ethernet | Shield / integriert | Netzwerkverbindung zu ARTA-PC |

## Motortreiber TB6600

Typische Zuordnung:

| TB6600 | Verbindung |
|---|---|
| PUL / STEP | Arduino D2 |
| DIR | Arduino D5 |
| ENA | Arduino D8, falls genutzt |
| Motor A+/A-/B+/B- | Schrittmotorwicklungen |
| VCC/GND Motor | 24-V-Netzteil |

Die genaue Beschriftung kann je nach TB6600-Modul abweichen.

## Netzteile

| Spannung | Zweck |
|---:|---|
| 24 V | Versorgung Motortreiber / Schrittmotor |
| 5 V | Arduino, Display und Logik, je nach Aufbau |

## Referenzsensor

Der Referenzsensor wird im Sketch an Pin D3 verwendet:

```cpp
#define Referenzpunkt 3
pinMode(Referenzpunkt, INPUT_PULLUP);
```

Der Code erwartet einen HIGH/LOW-Wechsel während der Referenzfahrt. Wenn die Referenzfahrt in die falsche Richtung läuft oder nicht endet, Sensorlogik und Verdrahtung prüfen.

## Wichtige Hinweise

- GND-Bezüge sauber planen.
- 24 V und 5 V nicht verwechseln.
- TB6600-Strom passend zum Motor einstellen.
- Microstepping notieren, weil es `Stepsprograd` beeinflusst.
- Vor dem ersten Test Motor ohne Last prüfen.

## Sicherheit

**Netzspannung ist gefährlich. Arbeiten an 230 V dürfen nur von fachkundigen Personen durchgeführt werden.**

Vor dem Einschalten kontrollieren:

- keine losen Litzen,
- Zugentlastung vorhanden,
- Netzteile berührungssicher verbaut,
- richtige Polarität,
- Not-Aus oder einfache Abschaltmöglichkeit.

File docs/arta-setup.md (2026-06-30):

# ARTA einrichten

ARTA kann externe Drehtellerprogramme verwenden. Dieses Projekt nutzt dafür die Datei:

```text
ARTA Turntable File/turntable.exe
```

## Einrichtung

1. ARTA starten.
2. Menü öffnen:

```text
Setup -> Rotating turntable
```

3. `External` auswählen.
4. Als Programm `turntable.exe` aus dem Ordner `ARTA Turntable File/` eintragen.
5. Falls ARTA die Datei nicht direkt auswählbar macht, den Pfad manuell eintragen.

ARTA Turntable File

## Gruppenmessung starten

1. Menü öffnen:

```text
Record -> Spatial impulse response group record
```

2. Turntable Driver auswählen.
3. Messordner auswählen oder neu erstellen.
4. Winkelauflösung einstellen, z. B. `15°`.
5. Endwinkel einstellen, z. B. `45°`, `90°` oder `180°`.
6. Pause eintragen, z. B. `3 s`.
7. Dateiname prüfen.
8. Start drücken.

ARTA Gruppenmessung

## Netzwerk

Der Arduino erhält seine IP-Adresse per DHCP und zeigt sie auf dem LCD an.

Im Sketch ist der UDP-Port festgelegt:

```cpp
unsigned int localPort = 10049;
```

Wenn keine Kommunikation stattfindet:

- IP-Adresse auf dem Display prüfen,
- Windows-Firewall prüfen,
- Netzwerkverbindung prüfen,
- sicherstellen, dass PC und Arduino im gleichen Netzwerk sind.

## Hinweis zur EXE

Aktuell liegt im Repository die fertige Windows-Datei `turntable.exe`. Für bessere Nachvollziehbarkeit sollte zusätzlich der Python- oder Quellcode dieser EXE veröffentlicht werden.

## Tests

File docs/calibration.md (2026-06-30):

# Kalibrierung

Der wichtigste Kalibrierwert im Arduino-Code ist:

```cpp
float Stepsprograd = 65.75;
```

Dieser Wert bedeutet:

```text
Motorschritte pro 1 Grad Drehtellerbewegung
```

Wenn der Drehteller nicht exakt auf den gewünschten Winkel fährt, muss dieser Wert angepasst werden.

## Wovon hängt der Wert ab?

- Motor-Schrittzahl, z. B. 200 Schritte pro Umdrehung
- Microstepping am TB6600
- Zahnrad / Ritzel
- Drehkranz-Übersetzung
- mechanisches Spiel

## Einfache Kalibrierung

1. Drehteller referenzieren lassen.
2. Einen gut messbaren Winkel anfahren, z. B. `90°`.
3. Tatsächlichen Winkel messen.
4. Neuen Wert berechnen:

```text
neuer Stepsprograd = alter Stepsprograd × Sollwinkel / Istwinkel
```

## Beispiel

Der aktuelle Wert ist:

```text
65.75
```

ARTA fordert an:

```text
90°
```

Der Teller fährt tatsächlich nur:

```text
87°
```

Dann:

```text
65.75 × 90 / 87 = 68.02
```

Der neue Wert wäre also:

```cpp
float Stepsprograd = 68.02;
```

## Empfehlung

Nach der Korrektur mehrere Winkel prüfen:

- 15°
- 30°
- 45°
- 90°
- 180°

Wenn kleine Abweichungen je nach Richtung auftreten, liegt wahrscheinlich mechanisches Spiel vor. Dann hilft:

- Ritzelspiel reduzieren,
- Zahnkranz prüfen,
- immer aus derselben Richtung referenzieren,
- Beschleunigung/Geschwindigkeit reduzieren.

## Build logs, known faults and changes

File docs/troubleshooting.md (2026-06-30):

# Troubleshooting

## Display zeigt keine IP-Adresse

Mögliche Ursachen:

- Netzwerkkabel nicht angeschlossen
- DHCP im Router nicht aktiv
- Ethernet-Shield nicht korrekt gesteckt
- falsches Board ausgewählt

Prüfen:

1. Serial Monitor der Arduino IDE öffnen.
2. Arduino neu starten.
3. Meldungen zu DHCP prüfen.

Im Code gibt es einen Fallback:

```cpp
IPAddress ip(165, 166, 167, 100);
```

Diese Adresse passt in den meisten Heimnetzwerken nicht und sollte bei Bedarf angepasst werden.

## Referenzfahrt bleibt hängen

Mögliche Ursachen:

- Sensor falsch angeschlossen
- Sensor invertiert
- Abstand Sensor/Trigger falsch
- Pin D3 nicht korrekt verbunden

Im Code:

```cpp
#define Referenzpunkt 3
pinMode(Referenzpunkt, INPUT_PULLUP);
```

Prüfen, ob der Sensor im Serial Monitor bzw. mit einem einfachen Testsketch HIGH/LOW korrekt wechselt.

## Motor dreht nicht

Mögliche Ursachen:

- 24-V-Netzteil aus
- TB6600 falsch verdrahtet
- Motorwicklungen falsch zugeordnet
- Enable-Signal falsch
- Treiberstrom zu niedrig

Prüfen:

- TB6600-Spannung
- Motorwicklungen mit Multimeter
- STEP an Arduino D2
- DIR an Arduino D5
- GND-Bezug

## Motor läuft falsch herum

Lösung:

- DIR-Logik ändern,
- Motorwicklung tauschen,
- Richtung im Code anpassen.

## Winkel stimmt nicht

Ursache ist meist ein falscher Kalibrierwert:

```cpp
float Stepsprograd = 65.75;
```

Siehe [`calibration.md`](calibration.md).

## Motor verliert Schritte

Mögliche Ursachen:

- Beschleunigung zu hoch
- Geschwindigkeit zu hoch
- Motorstrom falsch eingestellt
- Mechanik schwergängig
- Last zu groß

Im Code prüfen:

```cpp
stepper.setMaxSpeed(500);
stepper.setAcceleration(1000);
```

Zum Testen beide Werte reduzieren.

## ARTA startet keine Bewegung

Prüfen:

- Ist `turntable.exe` in ARTA eingetragen?
- Blockiert die Windows-Firewall?
- Ist Arduino im Netzwerk erreichbar?
- Wird die IP-Adresse auf dem Display angezeigt?
- Sind PC und Arduino im gleichen Netzwerk?

## Motor wird heiß

Mögliche Ursachen:

- Haltestrom am TB6600 zu hoch
- Enable/Disable nicht korrekt
- Motor bleibt dauerhaft bestromt

Im Sketch wird nach Bewegungen deaktiviert:

```cpp
stepper.disableOutputs();
```

Trotzdem Treiberstrom und Enable-Logik prüfen.

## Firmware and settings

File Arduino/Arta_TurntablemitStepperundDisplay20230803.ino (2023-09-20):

#include <Ethernet.h>
#include <EthernetUdp.h>
#include <Wire.h>  // Wire Bibliothek hochladen
#include <LiquidCrystal_I2C.h> // Vorher hinzugefügte LiquidCrystal_I2C Bibliothek hochladen
#include <AccelStepper.h>

LiquidCrystal_I2C lcd(0x27, 20, 4);  //Hier wird das Display benannt (Adresse/Zeichen pro Zeile/Anzahl Zeilen)

//define Pins for Stepper Interface
#define dirPin 5
#define stepPin 2
#define motorInterfaceType 1
#define EnPin 8

// Create a new instance of the AccelStepper class:
AccelStepper stepper = AccelStepper(motorInterfaceType, stepPin, dirPin);

//technical data for the turntable
//float Ballbearingteeth = 176;
//float Pinionteeth = 12;
//float stepspermotorrotation = 1600;
//float stepperspeed = 1; //Drehgeschwindigkeit  Wert in ms 

int Index;
//variable fuer counter
int count = 0;
int Position1;
int Position2;
int Nullposition;
float Stepsprograd = 65.75;

String line0 = "FM Audio";
String line1 = "ARTA Turntable";
String line2 = "";
String line3 = "";
String position;

//Pin für den Naeherungssensor definieren
#define Referenzpunkt 3

//    NETZWERK

// Enter a MAC address and IP address for your controller below.
// The IP address should match your local network:
byte mac[] = { 0xB8, 0x96, 0x74, 0x01, 0x02, 0x03 };
unsigned int localPort = 10049;      // local port to listen on

// buffers for receiving and sending data
char packetBuffer[UDP_TX_PACKET_MAX_SIZE];  // buffer to hold incoming packet,
char ReplyBuffer[UDP_TX_PACKET_MAX_SIZE];        // a string to send back

// An EthernetUDP instance to let us send and receive packets over UDP
EthernetUDP Udp;


// verschiedene Funktionen die verwendet werden


void lcdwriteline (int line,String Text){
  lcd.setCursor(0,line); //Text soll beim ersten Zeichen  in Reihe  line beginnen..
  lcd.print("                    ");
  delay(110);
  unsigned int StringLength = Text.length();
  int position = (20 - StringLength)/2;
  int cursor = (int)position;
  lcd.setCursor(cursor,line);
  lcd.print(Text);
  }

void referenzfahrt() {

  Serial.println("Fahre Turntable in Reset Position");
  lcdwriteline(3,"Fahre Referenz");
  
  if (digitalRead(Referenzpunkt) == HIGH) {

    stepper.setSpeed(500);
    while(digitalRead(Referenzpunkt) == HIGH) {  //While loop that SHOULD end if the input goes LOW
      //fahren 
      stepper.runSpeed();
    }
    Position1 = stepper.currentPosition();
  }

  if (digitalRead(Referenzpunkt) == LOW) {
    //in die entgegengesetzte Richtung fahren
    stepper.setSpeed(-500);
    while(digitalRead(Referenzpunkt) == LOW) {  //While loop that SHOULD end if the input goes HIGH
      //fahren
      stepper.runSpeed();
    }
    Position1 = stepper.currentPosition();

    //rechtsrum fahren
    stepper.setSpeed(500);

    while(digitalRead(Referenzpunkt) == HIGH) {  //While loop that SHOULD end if the input goes LOW
      //fahren
      stepper.runSpeed();
    }

    while(digitalRead(Referenzpunkt) == LOW) {  //While loop that SHOULD end if the input goes HIGH
      //fahren
      stepper.runSpeed();
    }
    Position2 = stepper.currentPosition();

    Nullposition = Position1 + ((Position2-Position1)/2);

    stepper.moveTo(Nullposition);
    stepper.runToPosition();
    delay(500);
    stepper.setCurrentPosition(0);
    stepper.disableOutputs();
    //end of if loop
    }

  
  lcdwriteline(3,"Am Referenzpunkt");
  Serial.println("Am Referenzpunkt angekommen.");

  }


void setup() {

// Open serial communications and wait for port to open:
  Serial.begin(9600);
  while (!Serial) {
    ; // wait for serial port to connect. Needed for native USB port only
  }

  //Display initialisieren und ersten Text schreiben 
  lcd.init(); //Im Setup wird der LCD gestartet
  lcd.backlight(); //Hintergrundbeleuchtung einschalten (0 schaltet die Beleuchtung aus).
  lcdwriteline(0,line0);
  lcdwriteline(1,line1);
  lcdwriteline(2,"Wait for DHCP");

  //Pin für den Naeherungssensor definieren
  pinMode(Referenzpunkt, INPUT_PULLUP); //Enable

  // start the Ethernet
  if (Ethernet.begin(mac) == 0)
  {
    Serial.println("DHCP Failed, using fixed IP");
    IPAddress ip(165, 166, 167, 100);
    Ethernet.begin(mac, ip);
    lcdwriteline(3,"DHCP FAILED");
    lcdwriteline(2,"FIXIP: 165.166.167.100");
  }
  else
  {
    Serial.println("Arduino connected to network using DHCP");
    //IP auf dem Display ausgeben
    char myIpString[24];
    IPAddress myIp = Ethernet.localIP();
    sprintf(myIpString, "%d.%d.%d.%d", myIp[0], myIp[1], myIp[2], myIp[3]);
    String myIps = "IP "+String(myIpString);
    lcdwriteline(2,myIps);
    line3 = myIps;
  }
  delay(1000);

  // start UDP
  Udp.begin(localPort);

  stepper.setMaxSpeed(500); //SPEED = Steps / second
  stepper.setAcceleration(1000); //ACCELERATION = Steps /(second)^2
 
  stepper.disableOutputs(); //disable outputs, so the motor is not getting warm (no current)

  
  //Referenzfahrt starten
  referenzfahrt();
}

void loop() {


  // if there's data available, read a packet
  int packetSize = Udp.parsePacket();

  if (packetSize) {
    Serial.print("Received packet of size ");
    Serial.println(packetSize);
    Serial.print("From ");
    IPAddress remote = Udp.remoteIP();
    for (int i=0; i < 4; i++) {
      Serial.print(remote[i], DEC);
      if (i < 3) {
        Serial.print(".");
      }
    }
    
    // read the packet into packetBuffer
    Udp.read(packetBuffer, UDP_TX_PACKET_MAX_SIZE);
    
    long steppaction = atol(packetBuffer);

    Serial.println("Wert steppaction");
    Serial.print(steppaction);

    delay(1000);

    
    float Pos = steppaction * Stepsprograd;
    int Position = (int)Pos;
    stepper.moveTo(Position);
    stepper.runToPosition();
    delay(1000);
    String acpos = String(steppaction);
    position = "Position: "+acpos+" Grad";
    lcdwriteline(3,position);
    delay(1000);
    stepper.disableOutputs();
    // Define String
    String reply = "Fahre Turntable auf Position "+String(steppaction)+" Grad";
    // Length (with one extra character for the null terminator)
    int reply_len = reply.length() + 1;
    // Prepare the character array (the buffer)
    ReplyBuffer[reply_len];
    // Copy it over
    reply.toCharArray(ReplyBuffer, reply_len);

    Serial.println("");
    Serial.println("");
    
    for(int i=0;i<UDP_TX_PACKET_MAX_SIZE;i++) packetBuffer[i] = 0;

    // send a reply to the IP address and port that sent us the packet we received
    Udp.beginPacket(Udp.remoteIP(), Udp.remotePort());
    Udp.write(ReplyBuffer);
    Udp.endPacket();

    
  
  delay(10);
  }

}

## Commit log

2023-09-20 Arduino File
2023-12-19 Create STL
2023-12-30 Anschlussplan Skizze
    5V Netzteil ist für den Arduino gedacht.
2026-06-30 docs: switch to non-commercial source license
